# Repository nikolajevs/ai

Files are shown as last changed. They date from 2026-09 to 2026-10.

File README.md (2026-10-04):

# GrowBox — контроллер гроубокса

Прошивка ESP32 и собственная плата управления освещением, вентиляцией, поливом и обогревом. Температура и влажность измеряются внешним SHT4x; настройки доступны через веб-интерфейс, расписания используют RTC, журнал сохраняется на microSD.

## Структура репозитория

| Папка | Содержимое |
| --- | --- |
| [software/](software/README.md) | Прошивка Arduino для ESP32, веб-интерфейс и инструкция по сборке |
| [hardware/](hardware/README.md) | Проекты KiCad 10, BOM, модели деталей, корпус и файлы изготовления |
| [tests/](tests/) | Автоматические тесты веб-интерфейса |
| [vps-docs/](vps-docs/README.md) | Инструкция по работе с удалённой KiCad-станцией |

## Аппаратная часть

- [PCB_V1](hardware/PCB_V1/README.md) — основной проект платы: вход 24 В, четыре слоя, размер до 100×100 мм.
- [cheap-version](hardware/cheap-version/README.md) — вариант платы с использованием имеющихся компонентов. Файлы изготовления и состояние проверок описаны в его [FAB.md](hardware/cheap-version/FAB.md).
- [Корпус](hardware/enclosure/README.md) — параметрическая модель для 3D-печати; перед использованием сверяйте её с выбранной версией платы.

## Начало работы

Для прошивки откройте `software/software.ino`; зависимости, загрузка веб-интерфейса и проверки описаны в [software/README.md](software/README.md).

Для платы откройте нужный проект KiCad: `hardware/PCB_V1/PCB_V1.kicad_pro` или `hardware/cheap-version/cheap-version.kicad_pro`. Инструкции по проверкам и изготовлению находятся в документации соответствующего проекта.

Правила работы с репозиторием — [AGENTS.md](AGENTS.md).

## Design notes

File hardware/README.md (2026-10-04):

# Плата GrowBox

Проект KiCad 10: [PCB_V1/PCB_V1.kicad_pro](PCB_V1/PCB_V1.kicad_pro).
Текущая ревизия — **0.22**. Схема, размещение и трассировка выполнены; Gerber и заказной BOM подготовлены. Состояние проекта и навигация — [PCB_V1/README.md](PCB_V1/README.md).

## Проверки

Из папки `hardware`, с установленным KiCad 10:

```sh
python check_all.py
```

При нестандартной установке задайте `KICAD_CLI` (путь к `kicad-cli`) и `KICAD_PYTHON` (Python с модулем `pcbnew`). На Windows можно запускать через `"C:\Program Files\KiCad\10.0\bin\python.exe"`.

Проверяются ERC, соединения схемы и платы, размещение, правила трассировки, расчёты, BOM, DFM и DRC. Команда завершается ошибкой при нарушениях или несоединённых площадках. Сохранённые отчёты — [review/](review/).

`python check_all.py --write` обновляет отчёты, изображения листов и BOM. Используйте его только при намеренном обновлении этих файлов.

## Работа с готовой платой

- После изменения схемы обновляйте плату через **Update PCB from Schematic** в KiCad. `sync_board.py` предназначен для неразведённой платы и отказывается менять разведённую.
- После изменения платы выполните проверки и пересоберите производственный архив по [FAB.md](PCB_V1/FAB.md).
- Скрипты `route_power.py`, `route_signals.py`, `route_complete.py` пересоздают трассировку; это не обычная проверка. Зафиксированный результат — файл платы. Подробности — [ROUTING.md](PCB_V1/ROUTING.md).

## Инструменты

| Задача | Скрипты / инструкция |
|---|---|
| Все проверки | `check_all.py`; отдельные проверки — `verify_*.py`, `check_fab.py` |
| Расчёты питания и меди | `analyze_led_power.py`, `analyze_power_path.py`, `analyze_copper.py` |
| Заказ деталей и оценка цены | [BOM.md](PCB_V1/BOM.md), `export_lcsc_bom.py`, `audit_bom_cost.py`, `estimate_jlc_assembly.py` |
| Gerber и сверловка | [FAB.md](PCB_V1/FAB.md), `export_fab.py` |
| 3D-модели | `models3d/mechanical.py`, `models3d/power.py`, `sync_models.py`; [источники](PCB_V1/PLACEMENT.md) |
| Одноразовая плата из склада | [cheap-version/README.md](cheap-version/README.md) — отдельный проект cheap-1 (копия схемы PCB_V1 с заменами деталей) |
| Корпус (3D-печать) | [enclosure/README.md](enclosure/README.md), `enclosure/enclosure.py`, `enclosure/check_enclosure.py` |

Правила веток и проверки — [AGENTS.md](../AGENTS.md). Работа с удалённой KiCad-станцией — [vps-docs/README.md](../vps-docs/README.md).

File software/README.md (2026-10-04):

# GI — ESP32 Controller

Автоматизированная система управления гроубоксом на базе ESP32: климат-контроль, освещение, вентиляция, автополив и обогрев с веб-интерфейсом управления и облачной телеметрией.

Аппаратная часть: [плата PCB_V1](../hardware/PCB_V1/README.md) — схема, трассировка, заказ деталей и файлы изготовления. Общее описание — в [README репозитория](../README.md).

## Возможности

- **Климат-контроль** — датчик SHT4x (температура/влажность), поддержание заданной температуры с гистерезисом
- **Освещение** — управление LED по расписанию день/ночь, яркость связана с температурным контролем
- **Вентиляция** — два независимых канала PWM-управления вентиляторами (fan1/fan2) с настраиваемыми мин/макс пределами
- **Автополив** — планировщик по дням недели (битовая маска), защита от повторного срабатывания
- **Обогрев** — реле обогревателя с гистерезисом, три режима расписания: день/ночь/всегда
- **Безопасность** — аварийное отключение при потере связи с датчиком SHT4x, защита от деления на ноль в расчётах
- **Веб-интерфейс** — вкладки настроек, интерактивные SVG-графики с тултипами, статика лежит в SPIFFS
- **Хранение данных** — логирование в CSV на SD-карту, настройки — в NVS (Preferences)
- **Облако** — телеметрия в Ubidots по HTTPS через отдельную FreeRTOS-задачу на Core 0

## Структура проекта

```
software/
├── software.ino     # основная прошивка ESP32
└── data/            # файлы веб-интерфейса (SPIFFS/LittleFS)
    ├── index.html
    ├── settings.html
    ├── script.js
    ├── settings.js
    └── style.css
```

## Технологический стек

- ESP32 (Arduino framework, ядро esp32 3.x — используется `ledcAttach()` и `entry.path()`)
- ESPAsyncWebServer + AsyncTCP
- SPIFFS (веб-интерфейс из `software/data/`, заливается через Tools → ESP32 Sketch Data Upload)
- RTClib (PCF8563 на плате 0.20 или модуль DS3231 — определяется автоматически; планирование день/ночь)
- Adafruit SHT4x
- SD-карта (CSV-логирование)
- Ubidots (облачная телеметрия, HTTPS)

## Как устроены данные

Всё, что задаёт пользователь, лежит в `struct Settings`, всё, что происходит сейчас, — в `struct State`. Обе структуры — простые данные без `String`, и между задачами они передаются только целыми копиями под спинлоком:

- `Settings` меняет только обработчик `/save-settings`: разбирает форму в свою копию и публикует её целиком. `loop()` раз в секунду берёт свежую копию, задача Ubidots — перед каждой отправкой.
- `State` пишет только `loop()`, в свою рабочую копию `state`, и публикует её в конце каждой итерации. Веб и Ubidots читают `stateSnapshot()`.

Каждая настройка описана одной строкой в таблице `SETTING_DEFS`: имя в форме и JSON, ключ NVS, диапазон, значение по умолчанию. Из неё работают загрузка из NVS, разбор формы, сохранение и `/api/settings`. Чтобы добавить настройку, нужно поле в `Settings` и строка в таблице; если тип строки не совпадёт с типом поля, прошивка не соберётся.

Ключи NVS в таблице менять нельзя: по ним уже прошитые платы читают сохранённые значения.

## Веб-API

| Метод | Путь | Назначение |
|---|---|---|
| GET | `/api/status` | Текущее состояние (снимок `State`) |
| GET | `/api/settings` | Все настройки. Пароли и токен **не отдаются** — только флаги `wifi_pass_set` / `ap_pass_set` / `ubidots_token_set` |
| GET | `/api/console` | Кольцевой буфер сообщений Serial |
| GET | `/api/log?date=YYYY-MM-DD` | CSV-лог за день. Формат даты проверяется строго |
| GET | `/api/files` | Последние файлы в корне SD |
| POST | `/api/clearlogs` | Удаляет из корня SD файлы `*.csv`. Именно POST: GET-версию можно было вызвать со сторонней страницы |
| POST | `/save-settings` | Сохранение настроек. Пустое поле пароля/токена = «не менять»; стереть пароль — галочкой «сеть без пароля» |
| POST | `/set-time` | Установка часов. Применяется в `loop()`, к I2C обращается только он |

## Примечание по безопасности

Учётные данные WiFi и Ubidots хранятся в NVS Preferences. В исходниках нет рабочих паролей и токенов. Все страницы и API требуют входа `admin` с индивидуальным паролем устройства (HTTP Digest). Изменяющие запросы дополнительно требуют CSRF-токен; очистка SD доступна только через POST.

Сохранённые пароли и токен не возвращаются через API. Пустое поле пароля/токена означает «оставить прежнее значение». Для открытой сети роутера и отключения облака есть отдельные флажки удаления секрета. Точка доступа самой платы всегда защищена паролем.

Ubidots использует HTTPS с проверкой сертификата через ISRG Root X1. Для проверки срока сертификата плата синхронизирует системное UTC-время через NTP; это не изменяет локальное расписание DS3231. При недоступности доверенного TLS-соединения данные не отправляются; небезопасного fallback нет. Корневой сертификат находится в `software/UbidotsCA.h` и может требовать обновления при смене цепочки сервера.

Локальный веб-интерфейс остаётся HTTP: Digest не шифрует содержимое страниц и форм. Используйте защищённую точку доступа/доверенную LAN, не публикуйте порт 80 в Интернет.

### Обновление существующего устройства

1. Прошейте `software/software.ino` и обязательно обновите файлы SPIFFS из `software/data/`: старый интерфейс не передаёт CSRF-токен.
2. Откройте USB Serial Monitor, 115200 бод, и перезагрузите плату. В USB-консоли появятся `AP password` и `Web login: admin / ...`. Эти строки не попадают в веб-журнал.
3. При первом запуске этой версии пароль точки доступа заменяется случайным. Переподключитесь с паролем из USB-консоли и войдите в браузере. Пароли сохраняются между перезагрузками.
4. Ранее опубликованные пароль роутера и токен Ubidots необходимо заменить у соответствующих провайдеров и в настройках платы. Удаление из текущего файла не отзывает секреты и не удаляет их из истории Git. Существующие значения в NVS сохраняются до явной замены пользователем.
5. Проверьте дату/время. При потере питания RTC, неверной дате или отсутствии часов при старте автополив блокируется до установки времени или восстановления валидного RTC. После последующего отказа часов используется резервный отсчёт от последнего корректного времени.

На чистом NVS обогрев выключен. Существующий выбранный пользователем режим сохраняется.

Генерируемые пароли администратора и точки доступа состоят из **8 символов** (цифры и заглавные латинские буквы без похожих `0`, `1`, `I`, `O`). При обновлении длинный пароль администратора заменяется; пароль AP старого формата — ровно 32 строчные шестнадцатеричные цифры — заменяется однократно. Это распознавание по формату: вручную заданный пароль того же формата также будет заменён. Остальные пользовательские пароли AP сохраняются. Новые значения видны в USB-консоли, повторного сброса при перезагрузке нет. CSRF-токен сохраняет прежнюю длину.

Настройки света находятся на отдельной вкладке «Освещение».

Полив измеряет длительность через `millis()`, включая его переполнение; изменение календарного времени или настроек длительности не меняет уже запущенный цикл. День запуска записывается в NVS **до** включения насоса. При ошибке записи насос не включается. После перезапуска прерванный полив не возобновляется и не повторяется в тот же день. При переводе даты назад новые поливы запрещены до дня, следующего за последней сохранённой отметкой.

### Сборка и проверки

Целевая конфигурация: двухъядерный ESP32 Dev Module, Arduino-ESP32 **3.3.8**. Arduino core 2.x не поддерживается (используется LEDC API 3.x).

Библиотеки проверяемой сборки:

- ESP Async WebServer 3.11.0, Async TCP 3.4.10;
- RTClib 2.1.4;
- Adafruit SHT4x Library 1.0.5, Adafruit BusIO 1.17.4, Adafruit Unified Sensor 1.1.15.

Команды выполняются из корня репозитория:

```sh
arduino-cli compile --fqbn esp32:esp32:esp32 software
node --test tests/settings.test.cjs
```

Каждая сборка автоматически выполняет compile-time проверки календаря, флагов потери питания DS3231 (OSF) и PCF8563 (VL), BCD и режимов 12/24 часа, резервного отсчёта, переполнения `millis()` и допуска полива из `SafetyTests.h`, без затрат памяти/времени на плате. Тесты интерфейса проверяют скрытие секретов, передачу CSRF во всех формах и POST при очистке.

После прошивки отдельно проверьте на стенде: отключение RTC во время работы; потерю его батарейки; перевод времени во время полива; перезагрузку в минуту полива; сохранение SSID с кавычкой; отказ в API без входа/CSRF. Проверка сборки не заменяет эти аппаратные проверки.

---

V.1

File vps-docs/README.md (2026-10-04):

# KiCad VPS workstation

Удалённая рабочая станция для репозитория `nikolajevs/ai`.

## VPS

- Ubuntu Server 24.04 LTS 64-bit
- 2 CPU cores
- 4 GB RAM
- 4 GB swap
- ~63 GB SSD
- 100 Mbps
- KiCad 10.0.6
- XFCE / X11
- TigerVNC
- noVNC
- Tailscale
- Git
- Python 3

На VPS также работает Telegram-бот `ss-bot` (Node.js/PM2). Сайты `my-app` и `todo-app` установлены, но выключены ради экономии ресурсов — см. раздел [Telegram-бот и PM2](#telegram-бот-и-pm2).

## Текущий режим: без графики

С 2026-09-29 VPS работает без графической среды: `kicad-vnc` и `kicad-novnc` остановлены и убраны из автозапуска, Tailscale Serve для noVNC снят. Это освобождает около 200 MB RAM в простое и убирает пики до ~2 GB, когда в VNC-сессии открывался KiCad.

Проверки проекта (`kicad-cli`, `check_all.py`) дисплей не требуют и работают как обычно. Разделы ниже про VNC/noVNC описывают конфигурацию на случай, если графика снова понадобится.

Включить графику обратно:

```bash
sudo systemctl enable --now kicad-vnc.service kicad-novnc.service
sudo tailscale serve --bg localhost:6080
```

Выключить снова:

```bash
sudo systemctl disable --now kicad-novnc.service kicad-vnc.service
sudo tailscale serve reset
sudo systemctl reset-failed kicad-vnc kicad-novnc
```

`reset-failed` убирает косметический статус `failed`: при остановке noVNC выходит с кодом 143, а `tigervncserver -kill` — с кодом 1, если X-сервер уже завершился.

---

## Архитектура

```text
Phone / PC
    |
    | HTTPS через Tailscale
    v
Tailscale Serve
    |
    v
noVNC 127.0.0.1:6080
    |
    v
TigerVNC 127.0.0.1:5901
    |
    v
XFCE / X11
    |
    v
KiCad 10
```

Порты `5901` и `6080` должны слушать только localhost и не должны быть открыты в публичный интернет.

Tailscale Funnel для KiCad не используется.

---

# Удалённый рабочий стол

## Проверка сервисов

```bash
systemctl status kicad-vnc.service --no-pager
systemctl status kicad-novnc.service --no-pager
```

Проверка портов:

```bash
ss -ltnp | grep -E '5901|6080'
```

Ожидается примерно:

```text
127.0.0.1:5901
127.0.0.1:6080
```

## Перезапуск

```bash
sudo systemctl restart kicad-vnc.service
sudo systemctl restart kicad-novnc.service
```

## Логи

```bash
sudo journalctl -u kicad-vnc.service -n 100 --no-pager
sudo journalctl -u kicad-novnc.service -n 100 --no-pager
```

---

# TigerVNC

Сервис:

```text
/etc/systemd/system/kicad-vnc.service
```

Конфигурация:

```ini
[Unit]
Description=KiCad XFCE TigerVNC desktop
After=network.target

[Service]
Type=oneshot
User=administrator
RemainAfterExit=yes
ExecStart=/usr/bin/tigervncserver :1 -localhost yes -geometry 1600x900 -depth 24
ExecStop=/usr/bin/tigervncserver -kill :1

[Install]
WantedBy=multi-user.target
```

XFCE startup:

```text
~/.vnc/xstartup
```

Содержимое:

```sh
#!/bin/sh

unset SESSION_MANAGER
unset DBUS_SESSION_BUS_ADDRESS

export XDG_SESSION_TYPE=x11
export XDG_CURRENT_DESKTOP=XFCE

exec dbus-launch --exit-with-session startxfce4
```

VNC password задаётся:

```bash
vncpasswd
```

---

# noVNC

Сервис:

```text
/etc/systemd/system/kicad-novnc.service
```

Конфигурация:

```ini
[Unit]
Description=KiCad noVNC web interface
After=kicad-vnc.service
Requires=kicad-vnc.service

[Service]
Type=simple
User=administrator
ExecStart=/usr/share/novnc/utils/novnc_proxy --listen 127.0.0.1:6080 --vnc 127.0.0.1:5901
Restart=on-failure
RestartSec=3

[Install]
WantedBy=multi-user.target
```

---

# Tailscale

Проверка:

```bash
tailscale status
tailscale ip -4
sudo tailscale serve status
```

noVNC публикуется только внутри tailnet:

```bash
sudo tailscale serve --bg localhost:6080
```

Доступ осуществляется по адресу вида:

```text
https://<hostname>.<tailnet>.ts.net/vnc.html
```

Tailscale Funnel не включать.

---

# KiCad

Версия:

```bash
kicad-cli version
```

Текущая установленная версия:

```text
10.0.6
```

Основной проект:

```text
~/kicad/main/hardware/PCB_V1/PCB_V1.kicad_pro
```

Запуск KiCad из SSH в существующей VNC-сессии (только когда графика включена):

```bash
DISPLAY=:1 kicad \
  ~/kicad/main/hardware/PCB_V1/PCB_V1.kicad_pro \
  >/tmp/kicad.log 2>&1 &
```

Проверка:

```bash
pgrep -a kicad
```

KiCad специально не запускается автоматически после reboot, чтобы экономить RAM.

## Глобальные таблицы библиотек

В проекте подключена только библиотека `GrowBox`, а стандартные библиотеки KiCad (`Device`, `power`, `Resistor_SMD`, `Capacitor_SMD` и т.д.) берутся из глобальных таблиц:

```text
~/.config/kicad/10.0/sym-lib-table
~/.config/kicad/10.0/fp-lib-table
```

Обычно их создаёт GUI KiCad при первом запуске. На VPS, где сначала использовался только `kicad-cli`, их нужно скопировать из шаблонов один раз:

```bash
cp --update=none \
  /usr/share/kicad/template/sym-lib-table \
  /usr/share/kicad/template/fp-lib-table \
  ~/.config/kicad/10.0/
```

Проверка:

```bash
ls -l ~/.config/kicad/10.0/*lib-table
```

Если таблиц нет, ERC выдаёт сотни ложных предупреждений `lib_symbol_issues` / `footprint_link_issues`, а DRC — `lib_footprint_issues` с текстом `The current configuration does not include the ... library`. В этом случае `check_all.py` завершается с ошибкой `ENVIRONMENT` и сообщением `KiCad library tables`: это проблема настройки машины, а не нарушения проекта.

---

# Проверка проекта

Основной скрипт:

```text
hardware/check_all.py
```

Запуск:

```bash
cd ~/kicad/main/hardware

KICAD_CLI=/usr/bin/kicad-cli \
KICAD_PYTHON=/usr/bin/python3 \
python3 check_all.py
```

`check_all.py` выполняет в том числе:

- ERC;
- экспорт netlist;
- `verify_netlist.py`;
- электрические расчётные проверки;
- проверку BOM;
- проверку PCB, разводки и технологичности (JLCPCB);
- DRC.

Ожидаемый результат: `ALL CHECKS PASSED`, exit code `0`; ERC 0 нарушений, DRC 0 нарушений и 0 неподключённых падов (плата разведена); `verify_routing.py` входит в запуск. Перед первым запуском на новой машине настройте глобальные таблицы библиотек (см. раздел KiCad выше).

Для обновления committed review-файлов:

```bash
python3 check_all.py --write
```

`--write` использовать только намеренно, когда нужно обновить артефакты проекта.

---

# GitHub

Репозиторий:

```text
nikolajevs/ai
```

SSH remote:

```text
git@github-ai:nikolajevs/ai.git
```

Основной checkout на VPS:

```text
~/kicad/main
```

Рабочие деревья:

```text
~/kicad/worktrees/
```

GitHub остаётся источником истины.

---

# SSH для GitHub

Для `nikolajevs/ai` используется отдельный SSH deploy key.

Alias:

```text
github-ai
```

Фрагмент `~/.ssh/config`:

```text
Host github-ai
    HostName github.com
    User git
    IdentityFile ~/.ssh/id_ed25519_ai
    IdentitiesOnly yes
```

Проверка:

```bash
ssh -T git@github-ai
```

Ожидается:

```text
Hi nikolajevs/ai! You've successfully authenticated...
```

Private SSH key никогда не коммитить в репозиторий.

---

# Git workflow для AI

Основной принцип:

```text
origin/main
    |
    +--- новая task branch
            |
            +--- ChatGPT / Claude
            +--- изменения
            +--- проверки
            +--- commit
            +--- push
            +--- review
            +--- merge
                    |
                    v
                  main
```

AI не должен работать непосредственно в `main`.

Одна задача = одна ветка.

Для параллельной работы желательно использовать отдельный Git worktree для каждой ветки.

Это особенно важно для:

```text
*.kicad_sch
*.kicad_pcb
```

Сложные merge conflicts в этих файлах не следует разрешать автоматически без визуальной проверки.

---

# Обновить main

```bash
cd ~/kicad/main

git fetch origin --prune
git switch main
git pull --ff-only
```

Рекомендуемые настройки:

```bash
git config pull.ff only
git config fetch.prune true
```

---

# Создать новую рабочую ветку

Пример:

```bash
cd ~/kicad/main

git fetch origin --prune
git switch main
git pull --ff-only

git worktree add \
  -b ai/layout-led \
  ~/kicad/worktrees/ai__layout-led \
  origin/main
```

Рабочий каталог:

```text
~/kicad/worktrees/ai__layout-led
```

---

# Подключить ветку, уже созданную AI на GitHub

Сначала:

```bash
cd ~/kicad/main
git fetch origin --prune
```

Затем:

```bash
git worktree add \
  --track \
  -b ai/layout-led \
  ~/kicad/worktrees/ai__layout-led \
  origin/ai/layout-led
```

Если локальная ветка уже существует:

```bash
git worktree add \
  ~/kicad/worktrees/ai__layout-led \
  ai/layout-led
```

---

# Список worktree

```bash
git -C ~/kicad/main worktree list
```

---

# Проверить AI-ветку

Пример:

```bash
cd ~/kicad/worktrees/ai__layout-led/hardware

KICAD_CLI=/usr/bin/kicad-cli \
KICAD_PYTHON=/usr/bin/python3 \
python3 check_all.py
```

---

# Открыть AI-ветку в KiCad

```bash
DISPLAY=:1 kicad \
  ~/kicad/worktrees/ai__layout-led/hardware/PCB_V1/PCB_V1.kicad_pro \
  >/tmp/kicad-ai-layout-led.log 2>&1 &
```

Не следует одновременно редактировать одну и ту же ветку из нескольких открытых KiCad-сессий.

---

# После merge ветки

Обновить main:

```bash
cd ~/kicad/main
git fetch origin --prune
git switch main
git pull --ff-only
```

Удалить старый worktree:

```bash
git worktree remove ~/kicad/worktrees/ai__layout-led
git worktree prune
```

Удалить локальную ветку после merge:

```bash
git branch -d ai/layout-led
```

---

# Ресурсы VPS

Быстрая проверка:

```bash
free -h
swapon --show
df -h /
uptime
```

Процессы по RAM:

```bash
ps aux --sort=-%mem | head -15
```

Интерактивный мониторинг:

```bash
htop
```

---

# Swap

На сервере используется:

```text
4 GB RAM
4 GB swap
```

Проверка:

```bash
free -h
swapon --show
```

Параметр:

```text
vm.swappiness=10
```

---

# Контроль диска

Проверить filesystem:

```bash
df -h /
```

Крупные каталоги:

```bash
sudo du -xhd1 / 2>/dev/null | sort -h
sudo du -xhd1 /home/administrator 2>/dev/null | sort -h
```

Файлы больше 500 MB:

```bash
sudo find /home/administrator \
  -xdev \
  -type f \
  -size +500M \
  -printf '%s %p\n' 2>/dev/null \
  | sort -n \
  | numfmt --field=1 --to=iec
```

---

# Telegram-бот и PM2

Node.js установлен через `nvm`. В неинтерактивных shell (systemd, агенты, `ssh host cmd`) `pm2` может отсутствовать в `PATH`, поэтому используется полный путь:

```bash
export PATH=/home/administrator/.nvm/versions/node/v24.21.0/bin:$PATH
```

## Приложения

| PM2 name | Путь | Статус |
|---|---|---|
| `ss-bot` | `/opt/SS_COM/src/index.js` | запущен, в автозапуске |
| `pm2-logrotate` | модуль PM2 | запускается вместе с PM2 |
| `my-app` | `/home/administrator/BRIDGE/server/index.js` | выключен |
| `todo-app` | `/home/administrator/todo-app/server.js` | выключен |

Бот читает `BOT_TOKEN` и остальные настройки из `/opt/SS_COM/.env` сам; SQLite — встроенный `node:sqlite` Node 24, пересборка `better-sqlite3` не нужна. Деплой бота описан в `/opt/SS_COM/DEPLOY.md`.

## Автозапуск

PM2 запускается systemd-сервисом `pm2-administrator.service` (создан через `pm2 startup`), который после reboot восстанавливает список из `~/.pm2/dump.pm2`. Сейчас в нём только `ss-bot`.

```bash
systemctl status pm2-administrator --no-pager
pm2 status
pm2 logs ss-bot --lines 50 --nostream
```

Процессы PM2 должны принадлежать `pm2-administrator.service`:

```bash
ps -eo pid,cgroup:50,args | grep -E 'God Daemon|SS_COM' | grep -v grep
```

Если `pm2` запустить вручную из сессии агента (например, `claude-remote.service`) при остановленном сервисе, демон окажется внутри этой сессии и погибнет при её перезапуске (`KillMode=control-group`). Правильный перезапуск:

```bash
pm2 kill
sudo systemctl start pm2-administrator
```

Сервис привязан к `~/.nvm/versions/node/v24.21.0`. Если эту версию Node удалить или сменить, нужно заново выполнить `pm2 startup` (он выведет команду с `sudo`) и `pm2 save`.

## Вернуть сайты

Список процессов до выключения сайтов сохранён в:

```text
~/.pm2/dump.pm2.before-ss-bot-20260929-164457
```

Запустить сайт и добавить его в автозапуск:

```bash
cd /home/administrator/todo-app && pm2 start server.js --name todo-app
cd /home/administrator/BRIDGE/server && pm2 start index.js --name my-app
pm2 save
```

`todo-app` и `ss-bot` работали на Node 24.21.0, `my-app` — на 24.18.0.

---

# PM2 logs

На VPS уже была проблема, когда PM2 logs заняли около 40 GB.

Главные файлы были:

```text
~/.pm2/pm2.log
~/.pm2/logs/my-app-error.log
```

Проверка:

```bash
du -sh ~/.pm2
du -sh ~/.pm2/logs
ls -lh ~/.pm2/logs
```

Очистить конкретный огромный лог без удаления файла:

```bash
truncate -s 0 ~/.pm2/logs/<application>-error.log
```

PM2 log:

```bash
truncate -s 0 ~/.pm2/pm2.log
```

---

# PM2 log rotation

Модуль `pm2-logrotate` уже установлен и запускается вместе с PM2. Проверить настройки:

```bash
pm2 conf pm2-logrotate
```

Первичная установка:

```bash
pm2 install pm2-logrotate

pm2 set pm2-logrotate:max_size 50M
pm2 set pm2-logrotate:retain 7
pm2 set pm2-logrotate:compress true
```

---

# Node.js / better-sqlite3

На VPS уже возникала ошибка ABI:

```text
better_sqlite3.node was compiled against a different Node.js version
ERR_DLOPEN_FAILED
```

В результате PM2 постоянно перезапускал приложение и быстро увеличивал error log.

Исправление:

```bash
pm2 stop <application>

cd <application-directory>
npm rebuild better-sqlite3

pm2 start <application>
```

Если не хватает build tools:

```bash
sudo apt install -y build-essential python3 make g++
```

---

# TigerVNC: display :1 already running

Ошибка:

```text
A X11 server is already running for display :1
```

Проверить реальные процессы:

```bash
pgrep -af 'Xtigervnc|Xorg|Xvnc|Xwayland'
sudo ss -ltnp | grep 5901
```

Проверить lock:

```bash
ls -l /tmp/.X1-lock /tmp/.X11-unix/X1 2>/dev/null
```

Если `Xtigervnc` действительно жив, сначала остановить процесс:

```bash
kill -TERM <PID>
sleep 2
```

Проверить:

```bash
ps -p <PID>
ss -ltnp | grep 5901
```

Только после остановки процесса можно удалить stale lock/socket:

```bash
sudo rm -f /tmp/.X1-lock
sudo rm -f /tmp/.X11-unix/X1
```

Затем:

```bash
sudo systemctl reset-failed kicad-vnc.service
sudo systemctl start kicad-vnc.service
```

---

# noVNC не открывается

Проверить:

```bash
systemctl status kicad-novnc.service --no-pager
ss -ltnp | grep 6080
```

Проверить backend VNC:

```bash
ss -ltnp | grep 5901
```

Проверить Tailscale:

```bash
tailscale status
sudo tailscale serve status
```

---

# KiCad AT-SPI warning

Предупреждение вида:

```text
AT-SPI: Error retrieving accessibility bus address
```

в VNC/XFCE-сессии само по себе не означает сбой KiCad.

Проверить процесс:

```bash
pgrep -a kicad
```

---

# systemd после reboot

Проверить:

```bash
systemctl status pm2-administrator --no-pager
pm2 status
tailscale status
```

Если графика включена, дополнительно:

```bash
systemctl status kicad-vnc.service --no-pager
systemctl status kicad-novnc.service --no-pager
sudo tailscale serve status
```

---

# Основные правила безопасности

1. Не открывать VNC `5901` в публичный интернет.
2. Не открывать noVNC `6080` в публичный интернет.
3. Не использовать Tailscale Funnel для KiCad.
4. Не коммитить SSH private keys.
5. Не коммитить VNC passwords.
6. Не коммитить GitHub tokens.
7. Не коммитить Tailscale credentials.
8. AI работает только через отдельные ветки.
9. `main` обновляется из GitHub после merge.
10. Перед merge KiCad-изменений запускать проверки проекта.
11. Сложные конфликты `.kicad_sch` и `.kicad_pcb` проверять визуально.

---

# Краткая памятка

Обновить проект:

```bash
cd ~/kicad/main
git fetch origin --prune
git switch main
git pull --ff-only
```

Проверить VPS:

```bash
free -h
df -h /
```

Проверить бота:

```bash
systemctl status pm2-administrator --no-pager
pm2 status
```

Проверить Tailscale:

```bash
tailscale status
```

Проверить KiCad:

```bash
kicad-cli version
```

Запустить KiCad (только когда графика включена, см. «Текущий режим: без графики»):

```bash
DISPLAY=:1 kicad \
  ~/kicad/main/hardware/PCB_V1/PCB_V1.kicad_pro \
  >/tmp/kicad.log 2>&1 &
```

Проверить проект:

```bash
cd ~/kicad/main/hardware
KICAD_CLI=/usr/bin/kicad-cli KICAD_PYTHON=/usr/bin/python3 python3 check_all.py
```

---

# AI launchers

На VPS установлены OpenAI Codex CLI и Claude Code.

Безопасный запуск выполняется через wrapper-команды:

```bash
ai-codex <branch>
ai-claude <branch>
```

Примеры:

```bash
ai-codex ai/power-fix
ai-claude ai/layout-led
```

Wrapper:

- обновляет ветки через `git fetch`;
- запрещает работу напрямую в `main`;
- создаёт отдельный worktree в `~/kicad/worktrees/`;
- использует существующую ветку, если она уже есть;
- иначе создаёт новую ветку от `origin/main`;
- запускает агента внутри его worktree.

Codex и Claude могут работать параллельно только в разных ветках/worktree.

После запуска агент должен прочитать `AGENTS.md` и `vps-docs/README.md`.

Проверка KiCad из worktree:

```bash
cd hardware
KICAD_CLI=/usr/bin/kicad-cli \
KICAD_PYTHON=/usr/bin/python3 \
python3 check_all.py
```

Перед push:

```bash
git status
git diff
git push -u origin HEAD
```

После merge worktree можно удалить:

```bash
git -C ~/kicad/main worktree remove ~/kicad/worktrees/<worktree>
git -C ~/kicad/main worktree prune
```

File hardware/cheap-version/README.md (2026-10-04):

# cheap-version — одноразовая плата из того, что есть

Версия **cheap-1** платы GrowBox: те же функции и прошивка, что у PCB_V1 (ревизия 0.22), но детали берутся со склада пользователя, докупается только недостающее. Это отдельный проект, а не ревизия PCB_V1: `../PCB_V1/` не меняется.

**Решения пользователя (03.10.2026):** основа — копия схемы PCB_V1 с заменами; плата 4 слоя, 100×100 мм, стек как у PCB_V1 (1,6 мм, 1 oz снаружи / 0,5 oz внутри); ESP32-WROOM-32E на плате, прошивка и GPIO без изменений; J901 — винтовой клеммник KF301 вместо XT60, защиты от переполюсовки не нужно; L711 — Feryster DTMSS-27/0.047/15-V **на плате стоймя** (корпус будет выше); выходные 10 мкФ 100 В X7S докупаются, как в V1 (4,7 мкФ X7R со склада не берём).

**Решения пользователя (04.10.2026):** CH1 рассчитан на **80 Вт** (R716 0,12 Ом вместо 0,18; LED-панель допускает до 120 Вт, плата её не догружает), драйвер нагревателя — снова **UCC27524ADR** (как в V1) вместо IRS4427S, затем шина +12V и шелкография.

## Состояние

- **Схема готова к проверке** (`cheap-version.kicad_sch` + 6 листов). Её строит `tools/make_cheap1.py` из `../PCB_V1/` (от базовой схемы каждый раз заново). Остальные инструменты: `tools/sch_edit.py` — редактор текста схем, `tools/netdiff.py` — сравнение связности с PCB_V1, `tools/make_footprints.py` — свои футпринты (запуск Python из KiCad), `tools/make_models3d.py` — их 3D-модели (CadQuery), `tools/analyze_led_cheap.py` — расчёт LED-boost. После ручных правок схемы в KiCad `make_cheap1.py` больше не запускать.
- ERC: **0 нарушений**. Связность у всех нетронутых выводов совпадает с PCB_V1 (`netdiff.py`: 0 различий).
- Свои футпринты и упрощённые 3D: `Diodes_PowerDI5`, `L_Feryster_DTMSS-27_V` (`libraries/`). BOM — `BOM_cheap1.csv`, `BUY_cheap1.csv` (см. ниже).
- **Плата `cheap-version.kicad_pcb` разведена, Gerber и сверловка выгружены; перед заказом остаются пункты ([FAB.md](FAB.md)).** 170 деталей, 4 слоя 100×100 мм; 0 пересечений courtyard и выходов за контур; все цепи соединены. ERC 0; DRC (с `.kicad_dru`) 0 нарушений, 0 замечаний, 0 неподключённых; `check_fab.py` 0 FAIL / 2 WARN; `tools/run_checks.py` 9 из 9. Силовая медь входа, PTC, +24V к LED и узлов каналов усилена, линия вентиляторов +12V расширена, добавлен C911 у U902, шелкография очищена (см. ниже). JLCDFM (04.10.2026): единственное правило с Danger — зазор сквозных площадок до SMD-площадок (сборочное, платы не касается), остальное предупреждения, разбор в [FAB.md](FAB.md), раздел 6. Остаются: измерения на макете и корпус.
- Склад: [stock/components-20261003.csv](stock/components-20261003.csv); в схеме поле `Source` = `stock:<id>`, у покупных деталей пусто. Даташиты — [datasheets/](datasheets/README.md) (PDF в git не хранятся).

## Что заменено

| Блок | PCB_V1 | cheap-1 | Склад (id, шт) |
|---|---|---|---|
| 24→12 В (U902) | LMR16020PDDAR | **ST1S14PHR**; R906 (RT) убран | 26: 3 |
| 12→3,3 В (U101) | TPS54202DDCR | **ST1S10PHR**; L101 4,7 мкГн (FXL0630-4R7-M, тот же корпус); R102 31,6 кОм; C103 — не BOOT, а VIN_A (2,2 мкФ) | 27: 4 |
| Нагреватель PTC | UCC27524ADR, NTMFS5C628NL | драйвер **UCC27524ADR как в V1** (ENA на +12V, ENB на GND; было IRS4427S, 04.10.2026), **IRL2505** TO-220 | — (покупается); 78: 1 |
| LED-boost, ключи Q711/Q721 | AOD66923 | **BSC146N10LS5** (TDSON-8-1) | 112: 2 |
| LED-boost, диоды D711/D721 | SS5P10 | **SBRT15U100SP5** (PowerDI5, `GrowBox:Diodes_PowerDI5`) | 8: 5 |
| LED-boost, дроссель L711 | SRP1770TA-470M | **DTMSS-27/0.047/15-V** стоймя (`GrowBox:L_Feryster_DTMSS-27_V`) | 12: 1 |
| Диоды D521, D902 | SS36 | **SS56** (тот же SMC) | 20: 45 |
| Прочая керамика | см. BOM | 10 мкФ 50 В 1210 (C521, C710, C715, C725, C905, C906); 10 мкФ 35 В 1210 (C101, C602, C910); 22 мкФ 10 В 0805 (C104, C105, C401); 2,2 мкФ 16 В 0805 (C103, C203, C302); 10 мкФ 16 В 0805 (C201); 2,2 мкФ 50 В 1206 (C711, C721, C902); 100 нФ 0603 | 47+44; 6; 7; 57; 58; 3; 54 |
| Электролиты | C901 220 мкФ 50 В, C909 100 мкФ полимер | C901 **EEVFK1J471M** 470 мкФ 63 В (Ø16×16,5, футпринт CP_Elec_16x17.5); C909 **EEEFT1E821AP** 820 мкФ 25 В (Ø10) | 13: 1; 14: 1 |
| Резисторы | 0603 | 100 кОм/1 кОм 1 % 0603 (id 55, 62); 10 кОм, 4,7 кОм 0805 (id 70, 59, 72); 10 Ом и 47 кОм 1206 (id 41, 61) | см. CSV |
| Разъёмы | XT60PW-M, DORABO 3,5, KANGNEX 5,08, JST XH, TS-1187A | J901, J711/J721/J731: KF301-5,0-2P (MKDS-1,5-2 5,0); J302/J521/J601: FS1.5-02 3,5 мм; J501/J511: KF2510 4P (Molex KK-254); J301: XH угловой; SW201/SW202: тактовые 6×6×10 | 93; 86; 87; 90; 95 |

Остаётся как в V1 и докупается: UCC27524ADR (C185857, минимум 5 шт), шунт R716 0,12 Ом 2512 (FRM252WFR120TM той же серии, что был 0,18 Ом; номер на LCSC проверить), 7× Murata GRM32EC72A106KE05L (10 мкФ 100 В X7S, выходы LED), ESP32-WROOM-32E, PCF8563T и кварц, 2× AL8853S-13, microSD и держатель CR2032, TVS SMBJ26CA, предохранители и держатель F902, SOT-23 MOSFET, ESD-диоды, дроссели L721 и L902 и FXL0630-4R7-M, шунты, точные и мелкие резисторы и конденсаторы.

## Расчёты и проверка по даташитам

**ST1S14 (24→12 В).** Вход 5,5–48 В, VFB 1,222 В (1,202–1,239), предел тока 3,7–5,2 А, 850 кГц, BOOT 100 нФ, EN1 активный низкий (на GND), EN2 активный высокий (выше 1,5 В), PG не используется. Делитель R904 88,7 кОм 0,1 % + R905 10 кОм 0,1 %: 12,06 В, диапазон 11,9–12,2 В. L902 22 мкГн: пульсация 0,29–0,33 А, пик при 2 А — 2,17 А. EN2 через R907 470 кОм / R908 47 кОм: 1,96 В при 21,6 В, включение гарантировано от 16,5 В. Выходной электролит 820 мкФ (ESR 60 мОм): нуль 3,2 кГц, пульсация около 20 мВ; даташит допускает такие конденсаторы (fZ < BW < fSW/5), устойчивость проверить на макете.

**ST1S10 (12→3,3 В, DocID13844 Rev 7).** Выводы: 1 VIN_A, 2 INH (активный высокий; к VIN_A, если не нужен), 3 VFB, 4 AGND, 5 SYNC (на GND — 900 кГц), 6 VIN_SW, 7 SW, 8 PGND, EP — земля; вход до 18 В, VFB 0,8 В (0,784–0,816), предел тока 5 А, синхронный, диода нет. Делитель 100 кОм / 31,6 кОм: 3,33 В (3,26–3,40 В). Ток при бюджете 1 А: D = 0,28, пульсация 0,59 А на L 4,7 мкГн (диапазон даташита 0,6–1,2 А для 3 А), пик 1,3 А. Даташит проектирует контур под L 3,3 мкГн и C 22 мкФ (18,7 кГц); у cheap-1 L 4,7 мкГн и около 40 мкФ эффективных (3×22 мкФ 10 В): 11,6 кГц, нужна проверка реакции на скачок нагрузки. На входе по рекомендации для выходной ёмкости 47–100 мкФ: VIN_SW 10 мкФ (C101) и VIN_A 2,2 мкФ (C103). Потери около 0,37 Вт, нагрев около 15 К.

**Нагреватель.** Драйвер UCC27524ADR, как в PCB_V1 (IRS4427S убран 04.10.2026: его вход «1» от 2,5 В при минимуме 2,64 В у ESP32 давал запас всего 0,14 В). Выводы: 1 ENA (на +12V; в V1 на +3V3, но рядом нет места под переходное, даташит допускает неиспользуемый ENx на VDD, и внутренняя подтяжка к VDD всё равно держит канал включённым), 2 INA (HEATER_EN), 3 GND, 4 INB (GND), 5 OUTB (не подключён), 6 VDD (+12V), 7 OUTA (HEATER_DRIVE), 8 ENB (GND, канал B выключен). Входы по даташиту не зависят от VDD и рассчитаны на логику 3,3 В; затвор держит R602 100 кОм. IRL2505 при 4,2 А (100 Вт / 24 В): около 0,14 Вт без радиатора; 55 В выше ограничения входной TVS 42 В.

**LED-boost** (`tools/analyze_led_cheap.py`, результат — [review/LED_power_cheap1.txt](review/LED_power_cheap1.txt); модель PCB_V1, заменены только дроссель CH1, диоды и ключи). Все проверки модели проходят. **CH1 на 80 Вт** (R716 0,12 Ом, ток панели до 1,73 А с допусками): ток входа до 4,61 А, пик дросселя до 6,26 А (V1 при 53 Вт — 5,18 А; DTMSS держит 15 А), запас до OCP 2,06 А (R715 остаётся 0,027 Ом: окно OCP 8,3…14,1 А не выше точки 15 А дросселя), RMS дросселя 4,7 А, потери в диоде до 0,96 Вт, в обмотке 0,32 Вт без сердечника, субгармоники 0,18; консервативная оценка пульсации выхода 2,4 Vpp (при 53 Вт 1,6). Потолок канала на этом контроллере и дросселе: около 96 Вт (R716 0,10 Ом, запас OCP 1,13 А); при 120 Вт (R716 0,08 Ом) пик 8,57 А выше нижней границы OCP 8,32 А, канал начнёт упираться в ограничение — поэтому панель на 120 Вт подключается, но работает на 80 Вт. Предохранитель F711 (6,3 А, около 73 % от максимума входного тока) остаётся. CH2 без изменений (запас 0,97 А); выходная ёмкость как в V1. DTMSS-27 (даташит Feryster): 45,5 мкГн при 1 А, около 42 мкГн при 5 А, 26,1 мкГн при 15 А, RDC 10 мОм; в расчёте L = 47 мкГн −20 % и ещё −12 % на пике. BSC146N10LS5: RDS(on) 12,2 мОм типично, 14,6 мОм максимум при 10 В (у AOD66923 11 мОм); Qg 7,6 нКл, Qgd 2,8 нКл (3,5 нКл у AOD66923); выводы S1–S3, G4, D5–8, как в символе.

## Плата: как получено размещение

```sh
python tools/make_cheap1.py                                     # схема
kicad-cli sch export netlist --format kicadxml -o netlist.xml cheap-version.kicad_sch
"C:/Program Files/KiCad/10.0/bin/python.exe" tools/make_board.py netlist.xml      # плата из PCB_V1 без меди, футпринты заменены на месте
"C:/Program Files/KiCad/10.0/bin/python.exe" tools/auto_place.py --steps 80000 --seed 4 --write
"C:/Program Files/KiCad/10.0/bin/python.exe" tools/placement_report.py            # пересечения courtyard и выход за контур
```

`make_board.py` переносит позиции PCB_V1 (55 заменённых футпринтов остаются на своих местах), убирает R906 и обновляет цепи. `auto_place.py` — отжиг по габаритам courtyard (Python из KiCad только читает и пишет плату): энергия = длина цепей (HPWL, без GND) + штраф за смещение от позиции V1 и за поворот + штраф за пересечение и выход за контур. Закреплены ESP32, разъёмы, батарейный держатель, контрольные точки; вручную заданы дроссель L711 (70,9; 120,0; пады на 62,15 и 79,65 мм), J901 вплотную к левому краю (56,3; 62,0) и шунт R716 между клеммами J711 и J721 (Kelvin-метка NT712 едет с ним). Из пяти запусков (seed 1–4 легальны, длина цепей 2433–2465 мм) взят seed 4. Результат — стартовая точка, а не окончательное решение: перед трассировкой плату стоит просмотреть в KiCad; шёлк и подписи не причёсаны.

## Трассировка: состояние (03.10.2026)

**Все цепи соединены:** 1012 дорожек, 231 переходное отверстие; заливки GND на F.Cu/In1.Cu/B.Cu и +3V3 на In2.Cu, пять дополнительных полигонов входа и нагревателя. [Текущий вид F.Cu](review/Routing_top.png). Размещение и назначения выводов сохранены.

Завершены земля, +3V3, AUX_VIN, затворы LED, возврат LED1, питание помпы и измерительное ответвление LED2_OUT. LED2_OVP переложена для доступа к R727. Возврат LED1 приходит на силовой вывод шунта R716, а не на Kelvin net-tie. Отвод к F521 выполнен шириной 1 мм на внешнем слое (расчётный запас помпы 0,5 А); 0,25 мм к R727 — только измерительная ветвь OVP, не питание светильников. Основные силовые пути этими ответвлениями не заменены.

**Проверки:** KiCad 10.0.5: ERC 0; DRC 0 неподключённых цепей, 0 нарушений зазоров/замыканий, 0 замечаний по шелкографии (после `fix_silk.py`; до него было 120: 57 пересечений, 48 над открытой медью, 15 у края). 170 компонентов и 445 электрических выводов соответствуют схеме (`tools/check_sync.py`); размещение без пересечений. `hardware/check_all.py` проходит для основной PCB_V1; эта проверка сама по себе не проверяет cheap-version.

**Исправление инструментов:** `route_power.py`, `route_signals.py`, `route_complete.py` загружают соответствующий `.kicad_pro` вместе с платой. Без него заливка через Python игнорировала зазоры классов: вместо 0,4–0,5 мм применялось 0,2 мм. Доводчик теперь учитывает зазоры обеих цепей, не снимает препятствия возле конечных площадок и не подставляет 0,25 мм для неизвестного силового соединения. Силовые и переключающие цепи пропускает для ручной работы; исключения — только указанные одиночные ответвления F521 и R727. Последующая проверка CLI DRC обязательна.

**Усиление входа и PTC:** между J901 и F902 добавлена медь на F.Cu/B.Cu; +24V_LOADS от F902 к J601 перенесена с In2 на B.Cu. Сток Q601 связан с J601 полигонами на обоих внешних слоях. Площадки силовых THT подключены без терморазгрузки, возле истока Q601 добавлены четыре переходных отверстия Ø0,8/0,4 мм. Ответвление помпы переложено в обход полигона стока. Q601 остаётся вертикальным; размещение, схема и назначения выводов не менялись.

`tools/reinforce_input.py <board> --write` повторяемо обновляет только этот этап, сохраняя остальную трассировку. После него запускать `tools/verify_input_copper.py <board>` и CLI DRC. Проверка использует **фактически залитые** полигоны и контролирует непрерывные участки: вход — минимум 5,95 мм на каждом внешнем слое, питание нагревателя — 5,39 мм на B.Cu, путь стока — 1,75 мм на каждом внешнем слое. Это геометрическая проверка выбранных участков, а не тепловая квалификация всей платы: контактные сужения, металлизация отверстий и распределение тока между слоями требуют итоговой проверки. Остальные силовые цепи описаны ниже.

**Усиление +24V к LED и узлов каналов (04.10.2026):** кольцо +24V на In2 0,5 oz (95 мм, 2 мм) от F902 к F711/F721 и участок LED2_OUT на In2 (0,8 мм, 43 мм) убраны; вместо них внешние слои:

| Участок | Медь | Непрерывная ширина |
|---|---|---|
| +24V через полосу +24V_LOADS | входной полигон F.Cu продолжен под вершину полосы (кромка полосы: y = 157 − x), 10 переходных Ø0,8/0,4 вдоль неё | 7,2 мм до переходных |
| магистраль к CH1 и CH2 | B.Cu, полигон x 71–81,6, y 80–110 | 3,6 мм на самом узком месте |
| ветка к CH2 | B.Cu, полоса y 100–105,6 до F721 | 2,6 мм |
| питание F711 (CH1) | F.Cu, полигон 25×6 мм вместо полосы 2 мм, 12 переходных | 5,2 мм |
| питание F721 (CH2) | F.Cu, полигон + 6 переходных | 4,6 мм |
| LED1_VIN / LED2_VIN | F.Cu, полигоны вместо дорожек 2 мм | 2,2–2,9 мм |
| LED1_SW / LED2_SW | F.Cu, полигоны вместо дорожек 1,5 мм | 4,0–5,0 мм |
| LED2_OUT | B.Cu, 1,2 мм вместо In2 0,8 мм (около 45 мм) | 1,09 мм |

Оценка по IPC-2221 (1 oz, внешний слой): магистраль 3,6 мм при максимуме расчёта (CH1 на 80 Вт 4,61 А + CH2 1,29 А = 5,9 А) даёт около +9 К, полигоны LED1_VIN шириной 2,2 мм при 4,6 А около +12 К на коротком участке. Не менялись: LED1_OUT (0,8 мм на F.Cu, достаточно для 1,67 А), истоки Q711/Q721 (1,5 мм), возвраты, шина +12V.

`tools/reinforce_led.py <board> --write` повторяемо перестраивает только этот этап (зоны `auto:led-stage:*`, нужные дорожки и переходные; ставить после `reinforce_input.py`). `tools/verify_led_copper.py <board.json>` (JSON из `export_view.py`; Python с numpy, scipy и Pillow) считает по залитой меди ширину самого широкого непрерывного пути между точками и число переходных; `tools/freespace.py` — вспомогательный поиск свободных коридоров при проектировании. Результат: `verify_led_copper.py` PASS, DRC (с `.kicad_dru`) 0 ошибок и 0 неподключённых.

**Шина +12V, шелкография, драйвер (04.10.2026):**

- `tools/reinforce_12v.py`: линия вентиляторов (0,68 А) шла по In2 шириной 0,5 мм около 45 мм (около +28 К по IPC-2221); сегменты вне тесного места расширены до 0,8 мм (около +11 К), 6,5-мм перемычка между двумя переходными и дорожкой ESP_IO0 остаётся 0,5 мм (рядом на внешних слоях места нет). Шире B.Cu не получается: коридоры 0,3–0,7 мм.
- `tools/swap_heater_driver.py`: U601 = UCC27524ADR (ENA на +12V короткой перемычкой к рядом идущей дорожке, ENB на GND), значение и MPN у R716 и U601 на плате; схема и плата сверены по всем выводам (расхождений нет), ERC 0.
- `tools/fix_silk.py` (+ `silk_model.py`): удалены 29 линий шелка, которые пересекали площадки или контур платы (корпуса J301, J302, J601, J521 за краем, оси L711 через площадки, перекрытие контуров C901/D901); **все 170 обозначений теперь на шёлке** (168 на F.Silkscreen, 2 на B.Silkscreen — C911 и держатель батарейки), 1,0 мм высотой и штрихом 0,2 мм. До 04.10 только 67 лежали на шёлке, а 103 — на слое F.Fab/B.Fab с высотой 0,8 мм: в KiCad они «видны», но в Gerber шёлка их нет. Проверка геометрическая, штрих против штриха, как в DRC (`silk_model.py`): зазор до шелка 0,18 мм, до площадки 0,17 мм, до отверстий и переходных 0,2 мм, до края 0,45 мм. Медиана расстояния обозначения от выводов своей детали 0,6 мм; в плотных местах 39 обозначений стоят дальше 2 мм (до 10 мм: NT721, TP301, R905, C304, R403, NT712, R307, C103, D303, R410) — там обозначение читается по соседству, а не вплотную. Повторный запуск ничего не меняет. Вид сверху: [review/Board_top_cheap1.png](review/Board_top_cheap1.png).

**Петли DC/DC, пути возврата, производство (04.10.2026, ветка `cheap-fab`):**

- **ST1S14.** Цепь AUX_VIN от входных конденсаторов C905/C906 до вывода VIN 7 была около 20 мм с двумя переходными, половина на B.Cu над потолком +3V3, а не над землёй: оценка петли 13 нГн (`tools/analyze_dcdc_loops.py`, формулы микрополоски над плоскостью и переходного, порядок величины, не моделирование). Добавлен **C911** (100 нФ 0603 со склада, снизу под выводами 6/7, переходное на землю рядом, второе AUX_VIN-переходное у вывода 7; `tools/add_c911.py`): петля 4,8 нГн, выброс на VIN при токе 3,7 А за 5 нс оценивается в 3,5 В над 25 В. Остальные петли в норме: ST1S10 4,4 нГн (C101 в 6,5 мм), boost CH1 и CH2 — диод → выходные конденсаторы 3,7 и 3,8 нГн, SW-узел 1,2 и 1,3 нГн, исток → шунт 1,3 и 0,9 нГн; вся коммутационная петля boost 15–16 нГн (в ней 7 нГн — возврат по In1 от C716/C726 к шунтам R715/R725, 22–24 мм), выброс на SW около 6,5 В (CH1) и 3 В (CH2) при 100-вольтовых ключах и диодах. Устойчивость контуров ST1S14/ST1S10 расчётом не проверена (внутренняя компенсация, модели нет): [review/Bench_checklist_cheap1.md](review/Bench_checklist_cheap1.md).
- **Земля и пути возврата** (`tools/check_return_paths.py`, по заливке): In1 — один кусок меди, 92 % платы, без островов; пустоты больше 8 мм² — зона антенны ESP32 (48 × 6 мм, так задумано), антиконтактные отверстия THT и две «щели» от массивов переходных (8 × 3 мм у питания F711, 6 × 5 мм у перехода +24V; в них нет сигнальных цепей). Самое узкое место земли от входной клеммы J901.1 до силовых каскадов: 7,9–8,5 мм для LED-шунтов и возвратов, 7,2 мм для истока нагревателя, 5,9 мм для U902, 5,5 мм для ESP32 (нужно ≥ 5 мм; 12 А по 8 мм 0,5 oz даёт около 8 мОм, плюс заливки F.Cu и B.Cu). Переключающие цепи над пустотой In1: AUX_VIN 2,2 мм (у переходных рядом с U902), остальные не дольше 3 мм; сигнальные переходные на B.Cu без земляного рядом (11 штук: медленные SD_CS, RTC_VBAT, FAN_TACH, затвор LED1 через 3,4 мм на B.Cu) — информация, не отказ.
- **Производство** — [FAB.md](FAB.md): Gerber и сверловка 12 файлов (`tools/export_fab_cheap.py`), `check_fab.py` 0 FAIL / 2 WARN (как у PCB_V1), исправления по нему (`tools/fab_touchups.py`, `fix_silk.py`). Всё одной командой — `tools/run_checks.py` (9 шагов, около 7 минут): 9 из 9. Загрузка в JLCDFM остаётся за вами.
- **Для оператора сборки** — [assembly/Assembly_cheap1.pdf](assembly/Assembly_cheap1.pdf), 34 страницы A4 на русском: правила, страница «Главное о полярности», 10 шагов сборки (общий план платы с отмеченными деталями, таблица деталей по номиналам с корпусом, MPN и источником), 16 «плоскостей» A1–D4 (по 25 × 25 мм, у каждой детали позиция и номинал, красные метки полярности и вывода 1), карточки полярности и ориентации по типам деталей, контроль после сборки. Не ставятся: контрольные точки TP, пары NT и C106 (DNP). Пересборка после изменения платы: `tools/export_assembly.py` (KiCad Python) → `tools/make_assembly_doc.py` (Python с Pillow и PyMuPDF, шрифт Arial из Windows).
- **Короткий лист для оператора** — [assembly/Assembly_cheap1_A4.pdf](assembly/Assembly_cheap1_A4.pdf), 4 страницы A4: SMD-детали (142 шт.) и выводные (17 шт.) отдельно, у каждой группы своя таблица «позиции — номинал — корпус — MPN — полярность — шаг — зона» (все позиции сразу, одна строка на тип детали) и одна большая схема установки во всю страницу (все позиции, красные метки полярности, сетка зон A–D × 1–4, внизу вид снизу с C911 или BT301; на схеме SMD неполярные детали зелёные, полярные оранжевые, номинал рядом с позицией там, где хватило места — у 110 из 141). Пересборка: `tools/export_assembly.py` → `tools/make_assembly_sheet.py assembly.json assembly/Assembly_cheap1_A4.pdf` (тот же дамп платы и тот же BOM, что у длинной инструкции). Схема SMD (страница 1) есть и отдельным листом **A3** — [assembly/Assembly_cheap1_SMD_A3.pdf](assembly/Assembly_cheap1_SMD_A3.pdf): та же картинка в 1,4 раза крупнее, номинал рядом с позицией у 140 из 141 деталей (на A4 — у 110); собирается тем же скриптом с ключом `--a3 assembly/Assembly_cheap1_SMD_A3.pdf`.

**Оставшиеся проверки и ограничения:**

- На собранном прототипе: устойчивость обоих DC/DC (ST1S14 с электролитом 820 мкФ и ST1S10 с 4,7 мкГн) и нагрев — на макете по [чек-листу](review/Bench_checklist_cheap1.md). Силовые таблицы `POURS`/`TRACKS` в `tools/route_power.py` пока пусты; полигоны заданы в `tools/reinforce_input.py` и `tools/reinforce_led.py`. Запуск начальной стадии `route_power.py` удаляет всю текущую трассировку — использовать только на рабочей копии при подготовке нового силового прогона.
- Итоговые ориентиры нагрузок: общий вход до 11,9 А, +24V_LOADS 5,8 А, HEATER_DRAIN 5,3 А; нулевое число разрывов и геометрическая ширина не подтверждают допустимый ток и нагрев.
- Загрузить архив в JLCDFM ([FAB.md](FAB.md), раздел 5), пересобрать корпус под потолок около 40 мм. Основной проект PCB_V1 этим изменением не затронут.

Для повторной доводки текущего результата: `route_complete.py <board>` (без `--write` — проверочный проход); заполнение зон — `route_power.py <board> --finish --write`. Рядом с рабочей копией платы нужны одноимённые `.kicad_pro` и `.kicad_dru`. Просмотр меди: `tools/export_view.py` + `tools/view.py`.

## BOM и закупка

Для [импорта в LCSC](https://www.lcsc.com/bom) используйте [BOM_LCSC_cheap1.csv](BOM_LCSC_cheap1.csv). В нём 37 позиций для **одной платы с учётом склада**, 868 деталей с округлением до минимальных партий из снимка цен. Строка 1 — заголовки, данные начинаются со строки 2; при импорте сопоставьте `Quantity` с количеством и `LCSC Part Number` с кодом LCSC. Множитель количества — 1. Батарейка CR2032 без кода LCSC исключена и приобретается отдельно. Текущие цены, наличие и кратность магазин уточнит при импорте. CSV обновляется вместе с BOM командой `python hardware/cheap-version/tools/export_bom.py`.

`tools/export_bom.py` по схеме и складу пишет [BOM_cheap1.csv](BOM_cheap1.csv) (72 строки, 160 деталей; без net-tie, контрольных точек и C106 DNP; плюс CR2032; сам предохранитель 10 А для F902 не закупается, у пользователя есть, закупается только держатель) и [BUY_cheap1.csv](BUY_cheap1.csv) (что докупить). Со склада идут 94 детали, докупается 66 деталей в 38 строках. Оценка заказа LCSC с минимальными партиями: **$33,86**, без CR2032, доставки и налогов. Для пяти позиций цены и наличие сверены 04.10.2026; остальные цены — снимок PCB_V1 от 28–30.09.2026, их наличие повторно не проверялось. Дата и ссылка указаны в колонке Note. Цены соседних номиналов больше не используются.

## Экспериментальный FDM-трафарет

Для пробной ручной пайки сделаны [полный STL 100×100 мм](stencil/cheap_full.stl), [полный 3MF](stencil/cheap_full_geometry.3mf) и [тестовый купон 40×40 мм](stencil/cheap_test.stl) под Bambu Lab A1 mini с соплом 0,4 мм и PLA. Купон охватывает плотную область платы около U601 и мелких пассивных компонентов; его лучше напечатать первым. Для прямого открытия в Bambu Studio есть также [3MF купона](stencil/cheap_test_geometry.3mf). Превью: [cheap_test_preview.png](stencil/cheap_test_preview.png).

Для сопла **0,2 мм** добавлен предпочтительный вариант: [тестовый 3MF](stencil/cheap_test_02_geometry.3mf), [полный 3MF](stencil/cheap_full_02_geometry.3mf), а также соответствующие [STL купона](stencil/cheap_test_02.stl) и [полной платы](stencil/cheap_full_02.stl). В нём отверстия расширены только на 0,03 мм; толщина остаётся 0,20 мм (два слоя по 0,10 мм). Файлы без суффикса `_02` оставлены как более грубый запасной вариант для сопла 0,4 мм.

Это однослойный трафарет толщиной 0,20 мм. Отверстия взяты из `F.Paste`, для FDM они расширены на 0,08 мм (вариант 0,4 мм) или на 0,03 мм (вариант 0,2 мм) и упрощены до прямоугольных контуров. Поэтому это проверка идеи, а не замена лазерному трафарету: сначала нужно проверить купон и количество нанесённой пасты. Для `_02` задать сопло 0,2 мм, слой 0,10 мм, первый слой 0,10 мм, ширину линии около 0,22–0,24 мм, без поддержек и разглаживания, с плоской ориентацией и бримом; перед печатью проверить слайс в Bambu Studio. Для старого варианта 0,4 мм оставить слой и первый слой 0,20 мм. Малые перемычки между соседними площадками всё равно нужно проверить на превью.

SCAD и генератор лежат в [stencil/](stencil/) и [tools/make_stencil.py](tools/make_stencil.py). Повторная генерация:

```text
python tools/make_stencil.py --scad stencil/cheap_full.scad --test-scad stencil/cheap_test.scad --expand 0.08 --thickness 0.20
openscad -o stencil/cheap_full.stl --export-format binstl stencil/cheap_full.scad
openscad -o stencil/cheap_test.stl --export-format binstl stencil/cheap_test.scad
```

Для варианта с соплом 0,2 мм:

```text
python tools/make_stencil.py --scad stencil/cheap_full_02.scad --test-scad stencil/cheap_test_02.scad --expand 0.03 --thickness 0.20
openscad -o stencil/cheap_full_02.stl --export-format binstl stencil/cheap_full_02.scad
openscad -o stencil/cheap_test_02.stl --export-format binstl stencil/cheap_test_02.scad
```

Для стенда добавлен трафарет с полем **15 мм по всем четырём сторонам**: [3MF 130,05×130,05 мм](stencil/cheap_full_02_margin15_geometry.3mf), [STL](stencil/cheap_full_02_margin15.stl) и [SCAD](stencil/cheap_full_02_margin15.scad). Поля оставлены пустыми для прижима рамкой; рабочее окно остаётся 100,05×100,05 мм. Генерация:

```text
python tools/make_stencil.py --scad stencil/cheap_full_02_margin15.scad --expand 0.03 --thickness 0.20 --margin 15
openscad -o stencil/cheap_full_02_margin15.stl --export-format binstl stencil/cheap_full_02_margin15.scad
openscad -o stencil/cheap_full_02_margin15_geometry.3mf --export-format 3mf stencil/cheap_full_02_margin15.scad
```

Если понадобятся поля только слева и справа, генератор поддерживает раздельные размеры: используйте `--margin-x 15 --margin-y 0`.

### Стенд для нанесения пасты

Сделан параметрический двухдетальный стенд: нижняя ванночка и шарнирная прижимная рамка. Нижняя деталь имеет наружный размер около 146×151 мм с учётом шарнира, карман под плату 100,65×100,65 мм и рельеф под нижний держатель CR2032 BT301. Рамка имеет окно 101×101 мм, два отверстия под передние винты M3 и шарнир под штифт Ø3 мм. Шарнир состоит из двух внешних петель основания и центральной петли рамки; осевой зазор между ними уменьшен до 1 мм, чтобы рамка не уезжала вдоль штифта. Ухо рамки одно, по центру задней кромки, ровно под своим коленом (36 мм, x −18…18); отверстие Ø3,5 мм под штифт вычитается из готового тела и свободно во всех трёх коленах (раньше ухо было сдвинуто на 18 мм и закрывало 29 % отверстия). **Петля печатается без поддержек:** ось штифта поднята на 1,85 мм (z = 8,45 мм), так что низ трубки лежит в одной плоскости с низом рамки и рамка ложится на стол целиком (раньше трубка торчала на 1,85 мм ниже кольца, на столе оказывалась одна трубка, а под кольцом было 8 792 мм² нависаний; теперь нависаний 70 мм² — нижняя дуга трубки, как у любого горизонтального цилиндра Ø7 мм); ухо основания — блок до оси на всю ширину колена, ухо рамки заканчивается на 0,8 мм за осью (иначе его угол врезается в кромку основания при открытии), отверстие под штифт — капля остриём вверх. Рамка открывается на 3…170° без пересечения с основанием (проверено в OpenSCAD по 8 углам). В первой версии поля трафарета сделаны по 15 мм со всех сторон, чтобы ракель начинал и заканчивал ход за пределами платы.

Файлы для печати: [нижняя часть 3MF](stencil/stencil_jig_base_geometry.3mf), [рамка 3MF](stencil/stencil_jig_frame_geometry.3mf), [нижняя часть STL](stencil/stencil_jig_base.stl), [рамка STL](stencil/stencil_jig_frame.stl) и [параметрический SCAD](stencil/stencil_jig.scad). Превью сборки: [stencil_jig_preview.png](stencil/stencil_jig_preview.png). **Пробная петля** (три колена по 12 мм и небольшие площадки, те же высоты и зазоры): [нижняя часть](stencil/stencil_jig_hinge_test_base.stl) и [верхняя часть](stencil/stencil_jig_hinge_test_frame.stl) — печатаются плашмя без поддержек примерно за 10 минут; в них проверяются посадка штифта Ø3 мм и ход петли до печати всего стенда. Экспорт отдельных деталей из OpenSCAD:

```text
openscad -o stencil/stencil_jig_base.stl --export-format binstl stencil/stencil_jig_base.scad
openscad -o stencil/stencil_jig_frame.stl --export-format binstl stencil/stencil_jig_frame.scad
openscad -o stencil/stencil_jig_hinge_test_base.stl --export-format binstl stencil/stencil_jig_hinge_test_base.scad
openscad -o stencil/stencil_jig_hinge_test_frame.stl --export-format binstl stencil/stencil_jig_hinge_test_frame.scad
```

Для первой печати стенда достаточно PLA, слоя 0,20 мм, 4 стенок, 25–35% заполнения, без поддержек и с бримом вокруг шарнирных ушек. В рамку можно наклеить тонкую полоску TPU, силикона или каптона: она компенсирует неровность PLA и не даёт пережать трафарет. В нижние карманы устанавливаются два M3-гайки; шарнир лучше собрать на гладком винте или прутке Ø3 мм. Перед серийной печатью нужно проверить посадку реальной платы: зазоры и положение рельефа BT301 вынесены параметрами в начало `stencil_jig.scad`.

| Ref | Артикул | LCSC | Проверенная позиция |
| --- | --- | --- | --- |
| R102 | 0603WAF3162T5E | [C25967](https://www.lcsc.com/product-detail/C25967.html) | 31,6 кОм, 1%, 0603 |
| R907 | 0603WAF4703T5E | [C23178](https://www.lcsc.com/product-detail/C23178.html) | 470 кОм, 1%, 0603 |
| R904 | RT0603BRD0788K7L | [C728599](https://www.lcsc.com/product-detail/C728599.html) | 88,7 кОм, 0,1%, 0603 |
| R716 | JER2512F3R120 (JIERR) | [C49164917](https://www.lcsc.com/product-detail/C49164917.html) | 0,12 Ом, 1%, 3 Вт, 50 ppm/K, 2512 |
| L101 | FXL0630-4R7-M | [C167220](https://www.lcsc.com/product-detail/C167220.html) | 4,7 мкГн |

**Держатель F902** — XFCN XF-508P-B-B, [C19727305](https://www.lcsc.com/product-detail/C19727305.html) (по странице LCSC на 04.10.2026 в наличии 45 625 шт., от $0,26). На [странице JLCPCB](https://jlcpcb.com/partdetail/C19727305) он числится как деталь только для монтажа PCBA, отдельно не продаётся: поэтому инструмент JLCPCB для заказа деталей показывает по нему «No matches found». Покупать держатель в LCSC (импорт `BOM_LCSC_cheap1.csv` его находит). Предохранитель 10 А (MINI, 0297010.WXNV) из закупки убран. Третья «не найденная» строка в том же инструменте (`Description / CUSTOMER PART NUMBER`) — это заголовок CSV, прочитанный как деталь; игнорировать.

R716 заменяет предположительный FRM252WFR120TM. По [даташиту JIERR](https://datasheet.lcsc.com/datasheet/pdf/02ae4b20613551dea68a63964573e262.pdf) корпус 6,4×3,2×0,8 мм, короткие торцевые электроды 0,9 мм (версия без L): они перекрывают существующие площадки 2512. Геометрия платы сохранена. Рассеяние около 0,33 Вт при 1,667 А; паспортные 3 Вт требуют соблюдения условий охлаждения и снижения мощности выше 70 °C. Номинал и допуск не изменены, ток CH1 остаётся прежним.

Склада хватает, но без запаса остаются: 10 мкФ 50 В (6 шт из id 47; ещё 2 шт id 44 без MPN), 470 мкФ 63 В, 820 мкФ 25 В, DTMSS-27, IRL2505 и обе BSC146N10LS5 — при ошибке монтажа их придётся докупать (электролиты EEEFT1E821AP и EEVFK1J471M на LCSC есть: C178593, C178728).

## DTMSS-27 на плате (вариант A)

Версия -V по даташиту Feryster (допуски ±10 %): тороид стоит на ребре, два провода Ø1,9 мм вниз с шагом 17,5 мм, выводы 20±5 мм (после установки подрезать), корпус 32,5 мм (диаметр) × 16 мм (ширина), окно 5 мм, зазор до платы не более 2 мм. Футпринт: отверстия Ø2,4 мм с КП Ø4,2 мм на (±8,75; 0) мм, габарит 16×32,5 мм, куртярд 22,2×36,2 мм; ось тороида вдоль линии выводов. **Высота над платой около 35 мм (до 38 мм)**: потолок корпуса `Z_CEIL` из `../enclosure/` придётся поднять с 21 до примерно 40 мм; на размещении дроссель ставить у края платы, не над мелкими деталями.

## План

1. Проверка схемы в KiCad (открыть `cheap-version.kicad_pro`).
2. ~~BOM cheap-1 и закупка~~ — готово, см. выше.
3. ~~Новая плата из схемы и размещение~~ — готово; **трассировка** — все цепи соединены, силовая медь усилена (вход, PTC, +24V к LED, узлы каналов); шина +12V, геометрические проверки DC/DC и шелкография завершены. Внешний JLCDFM и испытания прототипа остаются.
4. ~~Gerber и заказной BOM~~ — готово ([FAB.md](FAB.md)); пересчёт корпуса из `../enclosure/` под высоту и новые разъёмы — отдельно.

Вход J901 развёрнут входами проводов к левому краю. Проектное посадочное место
`TerminalBlock_KF301_1x02_P5.00mm_Horizontal_Input` имеет обратную нумерацию
относительно библиотечного MKDS: вывод 1 GND снизу (56,3; 62), вывод 2 +24V
сверху (56,3; 57). Отверстия и полярность сохранены. Корпус MKDS остаётся
приближённой 3D-моделью KF301.

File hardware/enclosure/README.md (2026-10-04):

# Корпус GrowBox для PCB_V1

Печатный корпус из двух деталей — **основание** и **крышка** — для платы 100×100 мм (ревизия 0.22). Крепление на стену ушками, вентиляция, FDM из PLA, крышка держится на защёлках без винтов. Модель параметрическая (CadQuery), построена по STEP-экспорту платы и проверена на пересечения с ним. **Не печаталась:** допуски защёлок и размеры вилок ответных разъёмов нужно проверить на первом отпечатке.

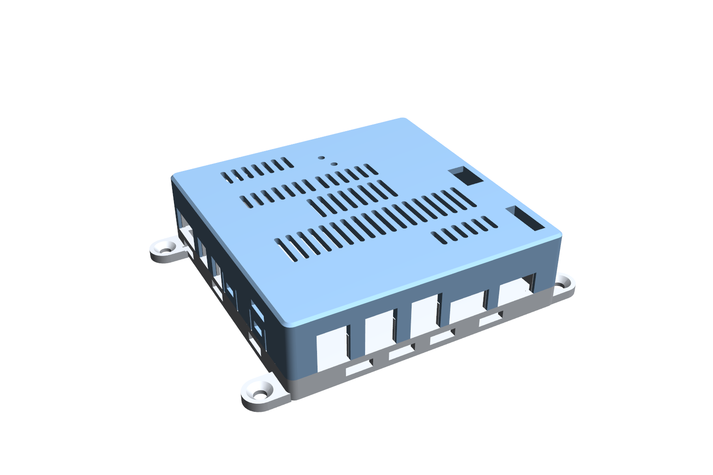
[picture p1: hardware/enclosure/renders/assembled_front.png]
Корпус, вид со стороны клемм


## Файлы

| Файл | Что это |
|---|---|
| `GrowBox_base.step`, `GrowBox_lid.step` | Детали в системе координат STEP платы (X = x KiCad, Y = −y KiCad, низ платы Z = 0): их можно загрузить вместе с `kicad-cli pcb export step` и посмотреть сборку |
| `GrowBox_base_print.stl`, `GrowBox_lid_print.stl` | Для печати, уже в печатной ориентации: основание — полом на стол, крышка — потолком на стол. Поддержки не нужны |
| `GrowBox_*_coupon_print.stl` | Фрагмент стенки 14 мм с защёлкой, основание и крышка. Печатать **первым** (около получаса) и проверить посадку |
| `enclosure.py` | Генератор. Все размеры и места вырезов — константы в начале файла |
| `check_enclosure.py` | Проверка по STEP платы: пересечения и зазоры |
| `render_enclosure.py` | Картинки в `renders/` |

## Конструкция

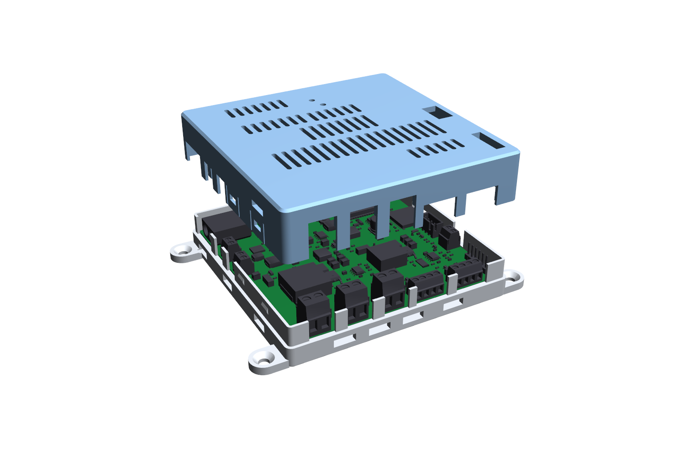
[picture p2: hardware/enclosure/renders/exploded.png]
Разнесённый вид


- Габарит 106×106×31,2 мм, с ушами 132 мм. Стенки 2,6 мм (кратно соплу 0,4 мм). Внутри 100,8×100,8: зазор до края платы 0,4 мм.
- Плата **лежит** на опорах (8 блоков 8×2 мм под рёбрами крышки и 4 угловых, верх опор на уровне низа платы) и прижимается сверху 8 рёбрами крышки на свободных участках края. Отверстий в плате не нужно. Опоры стоят только в местах, где снизу у края ничего нет; снизу плата занята лишь держателем BT301.
- От пола до платы 5,2 мм (низ BT301 −4,19 мм, зазор 1,01 мм), от платы до потолка 19,4 мм. Самая высокая деталь F902 (18,75 мм от низа платы) — зазор до потолка **2,25 мм**; высота F902 не измерена, см. «Что проверить».
- Стык «паз–шип»: на основании шип 1,2 мм (поднимается на 9 мм над плоскостью стыка z = 1,6 мм, то есть над верхом платы), на крышке внешняя юбка 1,2 мм, зазор 0,2 мм. Стык лежит на уровне верха платы, поэтому вырезы под разъёмы открыты в юбке и шипе сверху вниз, без перемычек.
- Защёлки: 7 окон 6 мм в юбке крышки (по трём сторонам) против гребней 0,6 мм на шипе основания. Юбка вокруг окна отделена щелями 0,8 мм и работает как гибкий палец (прогиб 0,4 мм, расчётная деформация около 0,7 %). Гребень скошен под 27° со стороны надевания крышки и под 23° со стороны снятия.
- Снять крышку: плоская отвёртка в прорезь у нижней кромки крышки (две: на верхней стороне, x = 82, и на правой, у верхнего угла, y = 62), затем приподнять по очереди каждую сторону.
- Стенное крепление: 4 уха, отверстие Ø4,5 мм с конусом под головку Ø8,6 мм; межосевое расстояние 120×92 мм. Крепёж в комплект не входит. Металла рядом с антенной ESP32 нет.

### Отверстия

Сторона и координаты даны по виду платы в KiCad (верх — край антенны ESP32, низ — клеммы светодиодов и вентиляторов).

| Где | Что | Окно |
|---|---|---|
| Слева | J901 XT60 (вилка ответного разъёма) | y 52,6…70,2, до z 11,2 |
| Слева | J601 PTC, J521 помпа | y 75,3…83,8 и 89,3…97,8, до z 10,8 |
| Снизу | J711, J721, J731 светодиоды (KANGNEX 5,08) | x 57,0…68,7, 74,0…85,7, 91,0…102,7, до z 16,3 |
| Снизу | J501, J511 вентиляторы | x 106,3…121,8 и 126,3…141,8, до z 10,8 |
| Справа | J401 microSD (карту вставлять и вынимать) | y 79,9…95,7, до z 4,65 |
| Справа | J302 поплавок | y 114,2…122,7, до z 10,8 |
| Потолок | J301 датчик SHT4x (XH, вилка сверху) | x 141,8…149,3, y 96,4…110,1 |
| Потолок | J201 UART (штыревая 1×6, Dupont сверху) | x 144,2…148,8, y 129,8…146,9 |
| Потолок | SW201 RESET, SW202 BOOT | трубки Ø6,4/Ø2,8, низ трубки z 4,5 (колпачок 3,1) — нажимать скрепкой или зубочисткой |

Вентиляция: щели в потолке над горячими узлами (вход питания и F902, Q601/U601, U902/L902/D902, U101/L101, драйверы светодиодов, Q501/Q511), горизонтальные щели в стенках крышки и щели в стенках основания под платой. Пол сплошной: он прижат к стене.

Клеммы затягиваются при снятой крышке; провода уходят в открытые вырезы.

## Печать

- Сопло 0,4, слой 0,2, 3 периметра, 4 верхних/нижних слоя, заполнение 20–25 %, без поддержек. Масса обеих деталей около 50–60 г (объём 38,5 + 39,8 см³ при сплошной модели).
- Мосты: щели в стенках 10 мм и окна защёлок 6 мм. Нужен обдув; при провисании уменьшить `BASE_SLOT_L` / `LID_SLOT_L`.
- **PLA размягчается около 55–60 °C.** Греющиеся ключи, диоды и дроссели пластика не касаются (до потолка не меньше 9 мм), но под нагрузкой проверьте температуру крышки и стенок на прототипе (цель из DESIGN: подъём SS5P10 ниже 50 °C). Если они нагреваются выше ~50 °C, печатайте из **PETG**: геометрия от материала не зависит.

## Проверка

`python check_enclosure.py` (в окружении с CadQuery; STEP платы выгружается через `kicad-cli`, путь к нему — `KICAD_CLI`) на ревизии 0.22:

- основание и крышка не пересекаются;
- ни одна деталь платы не пересекается с корпусом; 256 деталей из 295 заведомо дальше 2,5 мм от оболочки, остальные 39 проверены точно: **минимальный зазор 0,65 мм** (экран ESP32 до стенки), клеммы KANGNEX 0,8 мм, microSD 0,73 мм, кнопки до трубок 1,45 мм, F902 до потолка 2,25 мм;
- сама плата касается опор и низа рёбер по построению.

Ключевые сечения: [через защёлку](renders/section_snap.png), [через клемму](renders/section_front.png). Остальные виды: [без крышки](renders/open_top.png), [крышка изнутри](renders/lid_inside.png), [сзади](renders/assembled_back.png).

## Что проверить на первом отпечатке

1. Печать фрагментов-купонов: посадка шипа и гибкость пальца (нужны ли поправки `JOINT_GAP`, `RIDGE_P`, `SNAP_WIN`).
2. Высота F902 со вставкой: сейчас потолок 21,0 мм (`Z_CEIL`) при расчётной высоте 18,75 мм. После измерения проверить зазор и при необходимости изменить `Z_CEIL`.
3. Вилки ответных разъёмов (XT60, XH, Dupont) и провода в вырезах; 3D-модели разъёмов упрощены.
4. Крепёж (винты и дюбели) и фактическое направление монтажа.

## Пересборка

```sh
python -m pip install cadquery==2.8.0 vtk
python hardware/enclosure/enclosure.py
python hardware/enclosure/check_enclosure.py            # с --fast быстрее, без списка зазоров
kicad-cli pcb export step --force --no-dnp -o board.step hardware/PCB_V1/PCB_V1.kicad_pcb
python hardware/enclosure/render_enclosure.py board.step
```

При изменении расстановки платы пересоберите корпус и повторите проверку: окна и опоры привязаны к координатам разъёмов и свободным участкам края.

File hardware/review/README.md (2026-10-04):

# Review artifacts

Current revision **v22** (PCB_V1 0.22). Electrical, cost and assembly reports are produced by the check scripts from the `hardware` directory; do not edit generated reports by hand. Placement images are exported directly from KiCad; the final check log is captured from `check_all.py`.

| File | Content |
|---|---|
| `ERC_v22.rpt` | KiCad ERC report (0 errors / 0 warnings) |
| `DRC_placement_v22.rpt` | KiCad DRC of the placed, unrouted board before routing (0 violations; 341 unconnected links) |
| `DRC_routed_v22.rpt` | KiCad DRC of the routed board (0 violations, 0 unconnected pads); written by `check_all.py --write` |
| `LED_power_v22.txt` | `analyze_led_power.py` — LED boost sizing, 72 cases per channel |
| `Power_path_v22.txt` | `analyze_power_path.py` — input, fuses, TVS margins, 12 V buck, switches |
| `Copper_v22.txt` | `analyze_copper.py` — conductor widths, via counts and drops for the confirmed stack (1.6 mm, 1 oz outer, 0.5 oz inner) |
| `JLC_assembly_v22.txt` | `estimate_jlc_assembly.py` — JLCPCB PCB + assembly for 2 and 5 boards (fees, JLC part prices, joints, stock) |
| `BOM_cost_v22.txt` | `audit_bom_cost.py` — every schematic reference priced from `PCB_V1/price_snapshot_v22.json` (1 and 5 boards, MOQ, EUR) |
| `Checks_v22.txt` | Full `check_all.py` log for 0.22 |
| `Placement_v22_top.png` / `.svg`, `Placement_v22_bottom.png` / `.svg` | Placement exported from KiCad (top: F.Cu, F.Fab, F.Silkscreen, outline; bottom mirrored) |
| `Root_v22.png` … `LEDDrivers_v22.png` | Schematic sheets rendered from KiCad SVG export |
| `DFM_JLCPCB_v22.txt` | `check_fab.py` — the board against the published JLCPCB limits (0 FAIL, 2 WARN) |
| `Routed_v22_top.png`, `Routed_v22_bottom.png` | 3D renders (`kicad-cli pcb render`) of the routed board, top and bottom |
| `Routed_v22_F.png`, `Routed_v22_In1.png`, `Routed_v22_In2.png`, `Routed_v22_B.png` | Copper layers of the routed board (`kicad-cli pcb export svg`; B.Cu mirrored): GND pours red, white = clearance |

Only the current revision is kept here. When `REV` in `check_all.py` changes, delete the previous revision's files in the same commit. Reports of earlier revisions (v16–v21, and 0.1–0.15 under `history/`) are in git history; links are in the archive section of `../PCB_V1/CHANGELOG.md`.

The first routed layout of 0.22 (2026-10-01, `../PCB_V1/ROUTING.md`) adds `DRC_routed_v22.rpt`, the `Routed_v22_*` images and a `Checks_v22.txt` that includes `verify_routing.py`.

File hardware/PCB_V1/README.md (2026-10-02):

# PCB_V1 — контроллер GrowBox, ревизия 0.22

Открыть [PCB_V1.kicad_pro](PCB_V1.kicad_pro) в KiCad 10. После обновления репозитория перечитать открытый проект с диска перед сохранением.

**Состояние на 01.10.2026:** плата 100×100 мм полностью разведена; 170 компонентов, включая четыре net-tie. ERC — 0 ошибок и предупреждений, DRC — 0 нарушений и несоединённых связей. Gerber и заказной BOM готовы. Локальная DFM-проверка: 0 FAIL, два предупреждения; повторный JLCDFM и проверка механики ещё не подтверждены. Открытые вопросы — [DESIGN.md](DESIGN.md#открытые-вопросы).

## Основные параметры

- Вход **24 В**, XT60PW-M: 1 — GND, 2 — +24V; электронной защиты от переполюсовки нет.
- PTC 24 В / 100 Вт, помпа 24 В / около 6 Вт, два четырёхпроводных вентилятора 12 В.
- Свет: CH1 — панель 1,111 А; CH2 — две линейки параллельно, 0,465 А суммарно; общее управление яркостью. Возвраты разных каналов не объединять между собой или с GND.
- ESP32-WROOM-32E, PCF8563T + CR2032, microSD, внешний SHT4x и поплавок.
- Четыре слоя: 1 oz снаружи, 0,5 oz внутри; номинальная толщина 1,6 мм. Без крепёжных отверстий, разъёмы и microSD по краям, держатель батарейки снизу. Первые платы собираются вручную.

## Документация

| Задача | Документ |
|---|---|
| Понять схему, расчёты и нерешённые вопросы | [DESIGN.md](DESIGN.md) |
| Заказать детали | [BOM.md](BOM.md), [CSV для LCSC](BOM_LCSC_v22.csv), [XLSX](BOM_LCSC_v22.xlsx) |
| Заказать PCB | [FAB.md](FAB.md), [архив Gerber и сверловки](../fab/PCB_V1_v22_jlcpcb.zip) |
| Проверить механику, стек и 3D-модели | [PLACEMENT.md](PLACEMENT.md) |
| Напечатать корпус | [../enclosure/README.md](../enclosure/README.md) |
| Проверить трассировку | [ROUTING.md](ROUTING.md); расчётные ограничения — [ROUTING_PREP.md](ROUTING_PREP.md) |
| Проверить RTC и совместимость прошивки | [RTC_COMPATIBILITY.md](RTC_COMPATIBILITY.md) |
| Найти историю изменений | [CHANGELOG.md](CHANGELOG.md) |
| Запустить проверки | [../README.md](../README.md); сохранённые [отчёты](../review/) |

Справочные данные: [полный заказной BOM](BOM_PCB_V1_v22.csv), [состав схемы](BOM_schematic.csv), [карточки выбранных деталей](BOM_v0.1.md), снимки [цен LCSC](price_snapshot_v22.json) и [JLCPCB](jlc_snapshot_v22.json). Цены датированы 28–30.09.2026; стоимость компонентов и фактической корзины с минимальными партиями различается, см. [BOM.md](BOM.md).

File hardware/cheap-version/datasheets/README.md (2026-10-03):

# Даташиты cheap-1

PDF не хранятся в репозитории (`.gitignore`): положите файлы с этими именами сюда, чтобы скрипты и ссылки в `../README.md` работали.

| Файл | Деталь | Откуда |
|---|---|---|
| `ST1S10.pdf` | ST1S10 (3,3 В из 12 В) | ST, DocID13844 Rev 7, от пользователя |
| `Feryster_DTMSS-27.pdf` | дроссель DTMSS-27/0.047/15-V | Feryster, от пользователя |
| `IRS4426_IRS4427_IRS4428.pdf` | драйвер затвора нагревателя | Infineon/IR, DS 97481, от пользователя |
| `SBRT15U100SP5.pdf` | диоды LED-boost | Diodes Inc., DS36524 Rev. 9-2, от пользователя |
| `BSC146N10LS5.pdf` | ключи LED-boost | Infineon, Rev. 2.3, от пользователя |
| ST1S14 | 24→12 В | [st.com](https://www.st.com/resource/en/datasheet/st1s14.pdf) |

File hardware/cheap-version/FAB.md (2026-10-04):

# cheap-1 — файлы для производства на JLCPCB

04.10.2026. Плата `cheap-version.kicad_pcb` проверена и экспортирована в Gerber и сверловку; архив для загрузки — [fab/cheap-version_cheap1_jlcpcb.zip](fab/cheap-version_cheap1_jlcpcb.zip) (12 файлов, 498 КБ). Экспорт повторяем: `tools/export_fab_cheap.py --check` пересобирает архив и сравнивает с лежащим в репозитории. **Архив не загружался в JLCDFM и на jlcpcb.com** — это остаётся сделать вам (раздел 5).

## 1. Что в архиве

Gerber RS-274X (X2, формат 4.6, мм, расширения Protel) и Excellon, заголовки с датой и версией KiCad заменены константами, чтобы повторный экспорт давал тот же архив байт в байт. Состав тот же, что у PCB_V1 (см. [../PCB_V1/FAB.md](../PCB_V1/FAB.md)), префикс `cheap-version-`:

| Файл | Содержимое |
|---|---|
| `-F_Cu.gtl`, `-In1_Cu.g1`, `-In2_Cu.g2`, `-B_Cu.gbl` | четыре слоя меди (In1 — сплошная земля, In2 — сигналы и +3V3) |
| `-F_Mask.gts`, `-B_Mask.gbs` | паяльная маска, отверстия 1:1 с площадками, переходные закрыты |
| `-F_Silkscreen.gto`, `-B_Silkscreen.gbo` | шёлк: штрих 0,2 мм, текст 1,0 мм, не ближе 0,15 мм к площадкам, отверстиям и переходным; все 170 обозначений деталей напечатаны (168 сверху, 2 снизу) |
| `-F_Paste.gtp` | паста сверху (нижней пасты нет: единственная нижняя деталь C911 и держатель батарейки паяются вручную) |
| `-Edge_Cuts.gm1` | контур 100,000 × 100,000 мм |
| `-PTH.drl`, `-NPTH.drl` | сверловка: 284 металлизированных отверстия в 11 диаметрах (0,30 мм ×195 — переходные 0,3/0,65; 0,40 мм ×38; выводы 0,95–2,40 мм), 2 неметаллизированных Ø1,0 мм, пазов нет |

Экспорт читает свои файлы обратно и сверяет с платой: функции файлов, размер контура, самый узкий штрих меди (0,25 мм) и шёлка (0,2 мм), размеры и число отверстий.

## 2. Параметры заказа

Те же, что у PCB_V1: 4 слоя FR-4, 100 × 100 мм, 1,6 мм (стандартный стек JLC04161H-7628, импеданс не контролируется), медь 1 oz снаружи / 0,5 oz внутри, HASL (первые платы паяются вручную), маска и шёлк любого цвета, маска на переходных закрыта, минимальное отверстие 0,3 мм / 0,4 мм (наши 0,3/0,65 и 0,4/0,8 мм подходят без доплаты), 5 плат. Названия пунктов у JLCPCB меняются, сверьте по форме заказа.

## 3. Что проверено

`tools/run_checks.py` запускает всё сразу (9 шагов; для двух медных проверок нужен Python с numpy, scipy и Pillow в переменной `CHEAP_PY`). Отсутствие `CHEAP_PY` считается провалом, а не пропуском проверок. Результат на этой плате: **9 из 9**.

| Проверка | Итог |
|---|---|
| ERC | 0 нарушений |
| DRC с правилами проекта (`.kicad_dru`) | 0 нарушений и замечаний, 0 неподключённых цепей |
| Схема и плата по выводам (`check_sync.py`) | 445 выводов, 0 расхождений |
| Нормы JLCPCB (`../check_fab.py`) | **0 FAIL, 2 WARN** (те же два, что у PCB_V1: поясок переходных 0,175 мм при рекомендуемых 0,2 мм — стандартный заказ 0,3/0,4 мм выдерживается; 42 пары дорожек одной цепи ближе 0,25 мм без касания — узкие щели внутри одной цепи, замыкания нет) |
| Медь входа и PTC, медь +24V к LED | PASS (`verify_input_copper.py`, `verify_led_copper.py`) |
| Плоскость земли и пути возврата (`check_return_paths.py`) | PASS, подробности в README |
| Петли DC/DC (`analyze_dcdc_loops.py`) | PASS после C911, подробности в README |
| Архив совпадает с платой | OK |

Что нашёл `check_fab.py` на первой проверке и что исправлено: три переходных массива +24V стояли на площадке C901 (перенесены на 12 мест вне площадки; `reinforce_led.py`), девять одноцепных углов дорожек проходили у площадки на 0,03–0,085 мм без касания, и маска открывала их (объединены сегменты, угол LED2_RETURN у метки NT722 сдвинут на неё; `fab_touchups.py`), штрих шёлка 0,12–0,15 мм и шёлк ближе 0,15 мм к площадкам, отверстиям и переходным (`check_fab.py --fix-silk`, затем `fix_silk.py`; в `check_fab.py` текст сравнивается с линиями шёлка по штрихам, как в DRC, а не по рамке текста), подписи платы с версией «0.22» (теперь `CHEAP-1`).

## 4. Сборка вручную

Для оператора есть отдельные документы: [assembly/Assembly_cheap1_A4.pdf](assembly/Assembly_cheap1_A4.pdf) (4 страницы: схема установки A4 и таблица «позиции — MPN» отдельно для SMD и выводных деталей), схема SMD крупно на листе A3 — [assembly/Assembly_cheap1_SMD_A3.pdf](assembly/Assembly_cheap1_SMD_A3.pdf) — и подробная [assembly/Assembly_cheap1.pdf](assembly/Assembly_cheap1.pdf) (порядок, что куда ставить, полярность). Ниже — заметки по самой плате.

- Детали на нижней стороне: **C911** (100 нФ 0603 под U902, 1 шт; можно паять феном или паяльником сразу после установки U902, пока плата лежит вверх ногами) и держатель батарейки BT301.
- U601 теперь UCC27524ADR (SOIC-8); IRS4427S больше не нужна. ENA (вывод 1) соединён с +12V короткой перемычкой возле вывода: при пайке не соединить с соседним выводом 2 (HEATER_EN).
- L711 (DTMSS-27/0.047/15-V) стоит на ребре: выводы Ø1,9 мм (20 ± 5 мм по даташиту) подрезать после установки, зазор между тороидом и платой не больше 2 мм; корпус тороида лучше закрепить клеем или компаундом.
- R716 теперь 0,12 Ом (80 Вт), R715 остаётся 0,027 Ом. Шунт JIERR JER2512F3R120, C49164917: 1%, 3 Вт, 2512; источник и условия мощности — в README.
- Клеммник J901: KF301-5.0-2P (Cixi Kefa), по [странице LCSC](https://www.lcsc.com/product-detail/Screw-Terminal-Blocks_Cixi-Kefa-Elec-KF301-5-0-2P_C474881.html) 17 А / 250 В, провод 22–14 AWG (до 1,5 мм²). Расчётный максимум входа около 11,5 А (CH1 80 Вт, CH2, нагреватель 100 Вт, помпа, AUX), блок питания 24 В нужен от 250–300 Вт; провод к клеммнику ≥ 1,5 мм² и короткий.
- Список закупки и склада — [BOM_cheap1.csv](BOM_cheap1.csv), [BUY_cheap1.csv](BUY_cheap1.csv) (160 деталей, 94 со склада, 66 докупить; оценка заказа $33,86 без CR2032, доставки и налогов; предохранитель 10 А для F902 не закупается, только держатель XF-508P-B-B).

## 5. Перед заказом

1. Открыть `cheap-version.kicad_pcb` в KiCad (3D-вид, DRC) — автоматические проверки не заменяют просмотр глазами.
2. ~~Загрузить архив в JLCDFM~~ — сделано 04.10.2026, разбор отчёта в разделе 6.
3. Перед оплатой обновить цены и наличие по `BUY_cheap1.csv`: пять позиций сверены 04.10.2026, остальные цены взяты из снимка 28–30.09.2026; CR2032 приобретается отдельно.
4. Корпус (потолок около 40 мм под DTMSS, C901 Ø16, клеммники) пересобирается отдельно, см. `../enclosure/`.

## 6. Отчёт JLCDFM от 04.10.2026

[dfm.jlcdfm.com](https://dfm.jlcdfm.com), `cheap-version_cheap1_jlcpcb.zip`, только PCB DFM (SMT DFM не включался), 4 слоя, 10 × 10 см. В отчёте нет координат, места найдены сопоставлением с платой. Отчёт PDF лежит у пользователя, в репозиторий не добавлялся.

| Правило JLCDFM | Результат | Разбор |
|---|---|---|
| Ширина дорожки, зазор дорожек, зазор отверстия до дорожки, поясок, расстояние между площадками, острые углы, обрывы, дорожка и площадка до края, переходное в площадке и у площадки, перемычка маски, сверловка | замечаний нет или Good (дорожки 0,25 мм, зазор площадок 0,27, зазор отверстия до дорожки 0,39, поясок 0,17 мм) | — |
| **tht to smd** | **0,65 мм, Danger 18, Warning 18, Good 14** | Единственное правило с Danger, объяснение ниже |
| Solder mask opening exposing trace | 0,11 мм, Warning 1 (Good 57) | У PCB_V1 было Danger 1 и Warning 1. Остались одноцепные углы, где дорожка проходит у своей площадки на 0,09–0,12 мм без касания (Q601.2, R905.1, C712.1, R211.1, R908.1, C104.1); исправляются так же, как девять предыдущих (объединением сегментов), если понадобится |
| Negative soldermask expansion | 0,04 мм, Warning 52 | То же, что у PCB_V1 (50): отверстия маски совпадают с площадками 1:1, JLCPCB их принимает; расширение больше нуля сузило бы перемычки маски |
| Silkscreen to pad | 0,16 мм, Warning 54, Good 1 | Шёлк не ближе 0,15 мм к площадкам (норма JLCPCB); порог предупреждения JLCDFM не назван (судя по результату, выше 0,15 мм); в Gerber шёлк уже вычтен маской (`--subtract-soldermask`) |
| Silkscreen to hole | 0,15 мм, Warning 53, Good 6 | То же для отверстий и переходных |
| Silkscreen line width | 0,2 мм, Good 62 | — |

**tht to smd.** Измерение 0,65 мм на картинке отчёта совпадает с самой близкой парой «сквозная площадка — SMD-площадка» на плате: **L711.1 – C715.2** (по моему расчёту по контурам площадок это ровно 0,65 мм). Числа 18 / 18 / 14 сходятся, если Danger — пары ближе примерно 1,95 мм, а Warning — до примерно 2,9 мм (это моя догадка по числу пар, JLCPCB порог не называет). Пары ближе 1,95 мм: L711.1 – C715.2 (0,65), тактовые кнопки SW201 и SW202 (выводы THT) и соседние SMD-площадки ESP32 U201, C201, C203, R201, R202 (0,9–1,7 мм), держатель батарейки BT301 и TP103, C302, R304, F301 (1,06–1,7 мм), L711.2 – Q711 (1,93 мм). У PCB_V1 этих замечаний почти не было, потому что там кнопки SMD (TS-1187A) и L711 SMD, а у cheap-1 — кнопки со склада на сквозных выводах и тороид DTMSS.

Это норма для сборки (паяльная волна, выборочная пайка, зазор для оснастки), а не ограничение изготовления платы: между сквозной и SMD-площадкой остаётся не менее 0,65 мм меди-маски-меди. Плата паяется вручную, SMT-сборка JLCPCB не используется. Это моё заключение, JLCPCB его не подтверждал. Чтобы убрать эти замечания, пришлось бы заменить кнопки на SMD и сдвинуть C715, L711, BT301 и связанную разводку — на плате, рассчитанной на ручную пайку, смысла нет.

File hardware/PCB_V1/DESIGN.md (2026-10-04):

# PCB_V1 — описание схемы, ревизия 0.22

Текущая схема, расчётные допущения и открытые вопросы. История изменений и архив прежних отчётов — [CHANGELOG.md](CHANGELOG.md). Всё, что здесь сказано о соединениях, проверяется скриптами из `hardware/` (см. «Проверки»).

## Исходные данные

- Внешний БП **24 В**, уставка 24,0 В, не выше 25 В; расчётный диапазон силовой шины **21,6…25 В**.
- Нагрузки: PTC **24 В / 100 Вт**, помпа **24 В / около 6 Вт**, два 4-проводных PC-вентилятора **12 В**, LED-панель 16S18P (уставка 1,111 А) и две одинаковые «голые» LED-линейки под стабилизированный ток.
- ESP32-WROOM-32E, RTC PCF8563T с кварцем и резервной CR2032, microSD, SHT4x, поплавок. Назначение GPIO не менялось со времён 12-вольтовой версии. С 0.20 прошивка сама определяет микросхему часов (PCF8563 `0x51` или прежний DS3231 `0x68`), см. [RTC_COMPATIBILITY.md](RTC_COMPATIBILITY.md).
- Плата не больше 100×100 мм, без крепёжных отверстий; все разъёмы и microSD — по краям. Изготовитель JLCPCB, FR4, 4 слоя; **стек подтверждён пользователем: 1,6 мм, наружные слои 1 oz, внутренние 0,5 oz**. Все 170 компонентов (из них 4 net-tie без покупки) размещены внутри контура, батарейный держатель снизу. **Плата разведена** (01.10.2026, [ROUTING.md](ROUTING.md)). Правила и расположение — [PLACEMENT.md](PLACEMENT.md).

## Архитектура питания

```text
XT60 J901: 1=GND, 2=+24V
  +24V ─┬─ D901 SMBJ26CA, C901 220u/50V, C902
        ├─ F902 10 A ATM ─ +24V_LOADS ─┬─ PTC 24 V/100 W, Q601 (NTMFS5C628NL)
        │                             └─ F521 1 A ─ помпа 24 V/6 W, Q521 AO3422 + SS36
        ├─ C710 ─ F711 6.3 A ─ CH1 AL8853, панель 1,111 А
        │       └ F721 3 A ── CH2 AL8853, J721 ‖ J731 (0,465 А суммарно)
        └─ F904 3 A ─ AUX_VIN ─ LMR16020 (~526 kHz) ─ +12V ─┬─ F501/F511 1 A ─ вентиляторы
                                                           ├─ UCC27524A (затвор PTC ~12 В)
                                                           ├─ VIN обоих AL8853
                                                           └─ TPS54202 ─ +3V3 (логика)
```

- **Полярность** защищена только ключом разъёма XT60PW-M (вывод 1 «−», вывод 2 «+» по шелкографии посадочного места KiCad). Электронной защиты нет: неправильно собранный кабель выведет плату из строя. Кабель собирается один раз и проверяется мультиметром.
- **Участок XT60 — TVS — входная ёмкость не защищён предохранителем на плате**; нужна подходящая защита на стороне БП/кабеля.
- **+12V** — вспомогательная шина. Она отделяет от входных выбросов всё, что не рассчитано на 24 В с запасом: TPS54202 (≤28 В), UCC27524A (≤18 В), PC-вентиляторы, питание микросхем AL8853. Через 24 В идут только силовые дроссели LED, PTC и помпа.
- **LED-возвраты:** J721− и J731− соединены внутри CH2 и идут через шунт R726 на землю. Их нельзя соединять с J711− или с GND. При выключенном контроллере у boost остаётся путь вход — дроссель — диод — выход, поэтому КЗ на выходе ограничивают только F711/F721.

## LED-каналы

Расчёт — [LED_power_v22.txt](../review/LED_power_v22.txt): `analyze_led_power.py`, по 72 режима на канал (вход 21,6/24/25 В, Vf 40/44/48 В, 110/130 кГц, КПД 85/90 %, допуски FB и шунтов, снижение индуктивности). Это расчёт для выбора деталей, а не модель КПД и не гарантия защиты.

| Параметр | CH1, панель | CH2, обе линейки |
|---|---:|---:|
| Контроллер / ключ | AL8853 / AOD66923 (DPAK) | AL8853 / AOD66923 (DPAK) |
| Диод | SS5P10-M3/86A (TO-277A) | SS5P10-M3/86A (TO-277A) |
| Дроссель | SRP1770TA-470M | SRP1265A-470M |
| Шунт ключа / Rsl | 0,027 Ом / 1k | 0,047 Ом / 2,7k |
| Шунт тока LED | R716 0,18 Ом, FOJAN FRM252WFR180TM | R726 0,43 Ом |
| Ток номинальный / край допуска | 1,111 / 1,156 А | 0,465 / 0,484 А суммарно |
| Пик / RMS тока дросселя, макс. | 5,18 / 3,32 А | 3,08 / 1,63 А |
| Оценка OCP | 8,3…14,1 А | 3,9…7,9 А |
| Минимальный запас OCP над рабочим пиком | **3,14 А** | 0,94 А |
| Режимы | CCM, субгармоники ≤0,31 | DCM |
| Медь обмотки, 100 °C | 0,78 Вт | 0,31 Вт |
| Шунт ключа | 0,17 Вт | 0,07 Вт |
| Диод, проводимость (модель при 25 °C) | 1,05 Вт | 0,39 Вт |

Свет при 48 В: **75,66 Вт номинально / 78,72 Вт на границе допусков FB и шунтов**. Деление тока между двумя линейками CH2 не гарантируется; если одна оборвана, вторая получает не более 0,484 А. Затвор ключей получает около 12 В от питания AL8853. Насыщение дросселей в горячем состоянии, потери сердечника, пуск, OVP и компенсация петли расчётом не подтверждены.

## Компоненты и принятые решения

- **microSD:** HRO TF-01A (push-push). Пять подтяжек сохранены, отдельных ESD-сборок нет; карту менять при выключенной плате, риск статического разряда остаётся.
- **RTC:** PCF8563T, кварц FC-135 12,5 пФ, C304 18 пФ на OSCI. Резервное питание CR2032 через R307 1 кОм и D303 BAV170; зарядки нет. TP301 на CLKOUT служит для подбора C304. Схема питания, измерение частоты и ограничения — [RTC_COMPATIBILITY.md](RTC_COMPATIBILITY.md).
- **Выходные MLCC LED:** Murata GRM32EC72A106KE05L, X7S. По кривой Murata — 2,60 мкФ при 49 В, в модели 2,55 мкФ; эффективная ёмкость банка CH1 с допусками — 6,44 мкФ, расчётная граница пульсаций — 1,63 В p-p. Число конденсаторов без проверки петли и пульсаций не уменьшать. [Характеристики Murata](https://pim.murata.com/en-us/pim/details/?partNum=GRM32EC72A106KE05%23).
- **Измерение тока:** NT711/NT712/NT721/NT722 отделяют Kelvin-отводы от силовых площадок шунтов R715/R716/R725/R726.
- **L711:** SRP1770TA-470M сохранён. У рассмотренных дешёвых аналогов Isat 6,5–7,5 А; при принятом разбросе ограничения тока его снижение до этих значений опустило бы нижний порог ниже рабочего пика 5,2 А.

Текущие номиналы и MPN — [BOM.md](BOM.md). История замен и прежние цены — [CHANGELOG.md](CHANGELOG.md).

## Силовой путь и шина 12 В

Расчёт — [Power_path_v22.txt](../review/Power_path_v22.txt): `analyze_power_path.py`; сечения меди — [Copper_v22.txt](../review/Copper_v22.txt): `analyze_copper.py`.

- **PTC:** 4,17 А номинально, 4,79 А при холодном пуске (+15 %). Q601 при затворе ~12 В теряет 0,04–0,09 Вт.
- **Помпа:** 0,25 А номинально; в расчёте бюджет 0,5 А, реальный ток пуска и заклинивания не измерен.
- **TVS:** SMBJ26CA — рабочее 26 В > 25 В БП, ограничение 42,1 В при 14,3 А (10/1000 мкс, 25 °C). Запас до LMR16020 (65 В) — 22,9 В, до входных конденсаторов 50 В — 7,9 В. AL8853 на входной TVS больше не завязан. SMBJ26CA на стоке PTC (та же деталь, что D901) ограничивает до 42,1 В при VDS Q601 60 В; ключ помпы AO3422 (55 В) в худшем случае видит 42,9 В.
- **LMR16020:** делитель 150k/10k (0,1 %) даёт 12,000 В, статический разброс 11,74…12,26 В. Частота около 526 кГц (R906 47 кОм). Дроссель 22 мкГн PSPMAA0604-220M-ANP: пульсация ≤0,99 А p-p, пик ≤1,69 А при бюджете 1,2 А (потребность ~1,06 А). Минимальный порог тока микросхемы 2,5 А указан для 25 °C, максимальный 3,8 А ниже Isat дросселя 5 А; RMS обмотки 1,233 А при Irms 3,2 А, DCR ≤130 мОм. Выходная ёмкость: полимерный C909 25SVPF100M (100 мкФ/25 В) плюс керамический C910 22 мкФ. Без учёта C910 провал при ступени 0…1,2 А ≈0,18 В, пульсация ≈0,05 В p-p. Делитель EN 560k/47k: запуск ~14,9 В (13,0…17,3 В по разбросу порога).
- **TPS54202:** R101/R102 100k/22k 1%, 3,305 В номинально, 3,170…3,444 В статически при разбросе FB и сопротивлений. L101 FXL0630-100-M 10 мкГн: расчётный пик 1,496 А, RMS 1,040 А при бюджете логики 1 А; Isat 4,9 А / Irms 3,8 А при 25 °C — выше предела тока TPS54202 (не более 4,3 А). Выбросы нагрузки, дрейф и тепловой режим проверить на прототипе.
- **Входной ток платы:** ~11 А в худшем расчётном сценарии; БП 300 Вт = 12,5 А.

## Предохранители

Загрузка — с коэффициентом 0,75 (длительный ток) × 0,90 (запас на горячую плату, проектное допущение).

| Ref | Выбор | Допустимо с коэффициентами | Расчётная нагрузка |
|---|---|---:|---:|
| F902 | держатель XF-508P-B-B, вставка ATM 10 А | 6,75 А | 5,82 А (PTC + помпа) |
| F711 | Littelfuse 045106.3MRL, 6,3 А | 4,25 А | 3,32 А RMS |
| F721 | Littelfuse 0451003.MRL, 3 А | 2,03 А | 1,63 А RMS |
| F904 | Littelfuse 0451003.MRL, 3 А | 2,03 А | 1,09 А RMS |
| F501/F511 | Littelfuse 0451001.MRL, 1 А | 0,68 А каждый | 0,34 А каждый |
| F521 | Littelfuse 0451001.MRL, 1 А | 0,68 А | 0,50 А (бюджет) |

Отключающая способность, I²t и избирательность с реальным БП и кабелями не проверены. Вставка F902 — Littelfuse 0297010.WXNV (MINI 10 А, 32 В, отключает 1000 А при 32 В), см. [PRE_LAYOUT_PARTS_REVIEW.md](https://github.com/nikolajevs/ai/blob/1887d866ac820a41e9d1717056d188d7af6e6b51/pcb/PCB_V1/PRE_LAYOUT_PARTS_REVIEW.md). Площадки Littelfuse 451 — 1,96×3,15 мм по рекомендации производителя.

## Проверки

Запуск: `python check_all.py` из папки `hardware`; требования к окружению и обновление отчётов — [../README.md](../README.md).

| Проверка | Состояние ревизии 0.22 |
|---|---|
| ERC / DRC | 0 ошибок и предупреждений ERC; 0 нарушений и несоединённых связей DRC |
| Схема и плата | 116 групп соединений, 15 GPIO; 170 посадочных мест и 444 вывода сверены со схемой |
| Размещение и трассировка | Контур, доступ к разъёмам, модели, антенна, земля In1, узлы SW, Kelvin-линии и RTC; [ROUTING.md](ROUTING.md) |
| DFM | 0 FAIL, два предупреждения; повторная проверка JLCDFM не подтверждена — [FAB.md](FAB.md) |
| Расчёты и BOM | Отчёты и заказные файлы сверяются со схемой и датированными снимками цен |

Сохранённые результаты — [../review/](../review/). Проверки геометрии и связности не подтверждают устойчивость преобразователей и тепловой режим.

## Стоимость

По снимку 28–30.09.2026: **$30,04 компонентов на плату**, $28,42 при пяти платах. Это стоимость установленных деталей, а не корзины с минимальными партиями.

Заказ LCSC с минимальными партиями: **$59,92 на одну плату / $148,58 на пять**, без XT60, CR2032, доставки и налогов. Заказные файлы и исключения — [BOM.md](BOM.md); полный расчёт — [BOM_cost_v22.txt](../review/BOM_cost_v22.txt).

Первые платы собираются вручную: все SMT сверху, снизу THT-держатель батарейки. Оценка альтернативной сборки — [JLC_assembly_v22.txt](../review/JLC_assembly_v22.txt).

## Корпус

Печатный корпус из двух деталей (основание и крышка) лежит в [../enclosure/](../enclosure/README.md): настенное крепление ушками, вентиляция, FDM из PLA, защёлки без винтов. Плата без крепёжных отверстий лежит на опорах и прижимается рёбрами крышки; окна вырезаны по габаритам разъёмов из STEP платы, разъёмы J301 и J201 и кнопки BOOT/RESET доступны через потолок. По проверке STEP корпус и плата не пересекаются, минимальный зазор 0,65 мм. Корпус не печатался: посадку защёлок проверять на фрагментах-купонах.

## Открытые вопросы

1. **Закупка и образцы.** XT60PW-M на LCSC нет — покупать у другого поставщика; SRP1770TA-470M на LCSC было 26 шт. (28.09) — купить заранее; наличие перед покупкой проверить заново. На образцах проверить полярность и вылет XT60, клеммы и держатели, сторону ввода батарейки BT301 и **высоту F902 со вставкой**: сейчас она расчётная (17,15 мм), для корпуса закладывать не меньше 18 мм (потолок корпуса 21,0 мм, `Z_CEIL` в `enclosure/enclosure.py`); после измерения поправить `shoulder` в `fuseholder()` (`models3d/mechanical.py`), пересоздать STEP и повторить `enclosure/check_enclosure.py`. Есть оценка по датированному снимку; итоговая цена заказа ещё не подтверждена.
2. **Плата и производство.** Gerber подготовлены, локальные DFM-замечания исправлены; остаются повторная загрузка в JLCDFM и независимый просмотр Gerber — [FAB.md](FAB.md). В трассировке остаются два расчётных вопроса: HEATER_DRAIN 3,1 мм при требовании 3,02 мм и общая дорожка +12V к вентиляторам 0,5 мм на In2 (наружный расчёт к ней неприменим; при 0,682 А и толщине из файла платы 0,0152 мм требуется около 1,06 мм по принятой оценке IPC-2221, ΔT 10 °C). Это оценка сечения, не измерение температуры. Осмотр платы и проверка механики пользователем ещё не подтверждены.
3. На прототипе:
   - пуск, OVP и компенсация обоих boost; VGS при питании AL8853 от 12 В;
   - нагрев дросселей, ключей и TVS; нагрев SS5P10 в CH1 — цель: подъём ниже 50 °C с полигоном меди на катоде;
   - пуск и загрузка LMR16020; L902 PSPMAA0604 (новый производитель): индуктивность, нагрев при полной нагрузке 12 В, звон на SW; L101 FXL0630: нагрев и пульсации 3,3 В;
   - реакция защиты реального БП и предохранителей;
   - ток пуска и заклинивания помпы;
   - частота кварца RTC на TP301 (прошивка с `RTC_CLKOUT_TRIM 1`) и подбор C304, флаг VL после снятия батарейки;
   - батарейный узел RTC (D303 BAV170, R307) остаётся PROTOTYPE: RTC_VDD при +3V3 = 3,17/3,30/3,44 В, свежем и частично разряженном элементе; ток CR2032 в обоих направлениях при включённой и выключенной плате; сохранение времени и VL при пропадании и возврате питания; то же при крайних температурах;
   - фронты UART через R205/R206 1 кОм и реальная скорость прошивки с кабелем программатора.
4. PTC требует отдельного термостата или термопредохранителя с подходящим DC-рейтингом. На плате его нет.

## Источники

- [Diodes AL8853](https://www.diodes.com/assets/Datasheets/AL8853.pdf): VIN, FB/OCP, рампа, защиты.
- [TI LMR16020](https://www.ti.com/lit/ds/symlink/lmr16020.pdf): выводы, FB, предел тока, выбор ёмкости, пуск.
- [AOS AOD66923](https://www.aosmd.com/res/datasheets/AOD66923.pdf): Rds(on), заряды затвора, площадка DPAK.
- [Vishay SS5P10](https://www.vishay.com/docs/88984/ss5p10.pdf): VF, утечка, тепловое сопротивление, площадка TO-277A.
- [Bourns SRP1770TA](https://www.bourns.com/docs/Product-Datasheets/SRP1770TA.pdf), [SRP1265A](https://www.bourns.com/docs/product-datasheets/srp1265a.pdf): DCR, токи, посадочные места.
- cjiang FXL0630 ([LCSC C167223](https://www.lcsc.com/product-detail/C167223.html)), PROD Tech PSPMAA0604 ([LCSC C53190553](https://www.lcsc.com/product-detail/C53190553.html)): DCR, Isat, Irms, площадки.
- [Panasonic SVPF / 25SVPF100M](https://industrial.panasonic.com/ww/products/pt/os-con/models/25SVPF100M): ёмкость, ESR, корпус E7.
- [AOS AO3422](https://www.aosmd.com/sites/default/files/res/datasheets/AO3422.pdf): 55 В, RDS при затворе 2,5 В.
- [Littelfuse 451/453](https://www.littelfuse.com/assetdocs/fuse-451-and-453-datasheet?assetguid=533cd5cc-956c-4243-867f-6ab5a62f6ba1): предохранители и площадки.
- [Vishay SMBJ](https://www.vishay.com/docs/88392/smbj.pdf), [SS36](https://www.vishay.com/docs/88751/ss32.pdf): импульсные и тепловые условия.
- [Amass XT60PW-M](https://www.tme.eu/Document/b13629717d44ae038681dba08d18c0b6/XT60PW-M.pdf), XFCN XF-508P-B-B (чертёж LCSC C19727305).
- [NXP PCF8563](https://www.nxp.com/docs/en/data-sheet/PCF8563.pdf), Rev. 11.1: регистры, генератор, питание. Схема RTC и прошивка — [RTC_COMPATIBILITY.md](RTC_COMPATIBILITY.md).

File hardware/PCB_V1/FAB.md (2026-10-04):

# PCB_V1 — файлы для производства на JLCPCB, ревизия 0.22

01.10.2026, ветки `pcb-fab` и `pcb-dfm-fixes`. Разведённая плата ([ROUTING.md](ROUTING.md)) экспортирована в Gerber и сверловку; архив для загрузки — [../fab/PCB_V1_v22_jlcpcb.zip](../fab/PCB_V1_v22_jlcpcb.zip). Первый архив был проверен автоматическим анализатором JLCPCB (JLCDFM, отчёт прислал пользователь): он нашёл замечания по шёлкографии, маске и переходным отверстиям. Они устранены в плате и в архиве (раздел 3); **повторная загрузка архива в JLCDFM покажет, что осталось**.

## 1. Что в архиве

12 файлов, Gerber RS-274X (X2, формат 4.6, мм, расширения Protel) и Excellon:

| Файл | Содержимое |
|---|---|
| `PCB_V1-F_Cu.gtl`, `PCB_V1-In1_Cu.g1`, `PCB_V1-In2_Cu.g2`, `PCB_V1-B_Cu.gbl` | четыре слоя меди (In1 — земля, In2 — сигналы и +3V3) |
| `PCB_V1-F_Mask.gts`, `PCB_V1-B_Mask.gbs` | паяльная маска; отверстия равны площадкам (1:1), переходные закрыты маской |
| `PCB_V1-F_Silkscreen.gto`, `PCB_V1-B_Silkscreen.gbo` | шёлкография (штрих 0,2 мм, не ближе 0,15 мм к площадкам и отверстиям) |
| `PCB_V1-F_Paste.gtp` | паста сверху (для трафарета; нижней пасты нет — снизу только THT-держатель батарейки) |
| `PCB_V1-Edge_Cuts.gm1` | контур 100,000 × 100,000 мм (линия 0,05 мм по осевой) |
| `PCB_V1-PTH.drl`, `PCB_V1-NPTH.drl` | сверловка: металлизированные (329 отверстий, 8 диаметров, 2 фрезерованных паза) и неметаллизированные (2 × Ø1,0 мм, гнездо TF-01A) |

В заголовках файлов дата и версия KiCad заменены константами (`2000-01-01`, `10.0.0`), чтобы повторный экспорт давал тот же архив байт в байт.

## 2. Параметры заказа

Значения для формы заказа на [jlcpcb.com](https://jlcpcb.com/quote); названия пунктов у JLCPCB со временем меняются, сверьте по форме.

| Пункт | Значение | Почему |
|---|---|---|
| Base material / Layers | FR-4, **4** | |
| Dimensions | **100 × 100 мм** | нижняя ценовая категория JLCPCB; JLCDFM определил размер как 10 × 10 см |
| PCB Qty | 5 (минимум) | |
| Delivery format | Single PCB | панелизации нет |
| PCB Thickness | **1,6 мм** | стек подтверждён |
| Layer stack-up | стандартный 4-слойный 1,6 мм (JLC04161H-7628) | в проекте задан JLC7628; импеданс не контролируется |
| Outer / Inner copper weight | **1 oz / 0,5 oz** | подтверждённый стек, у JLCPCB это стандарт |
| Surface finish | HASL (со свинцом или без), ENIG — по желанию | первые платы паяются вручную: HASL проще и дешевле; ENIG даёт ровные площадки |
| Solder mask / Silkscreen | любой цвет / белый | |
| Via covering | Tented (по умолчанию) | в файлах маски на переходных нет отверстий |
| Min via hole size / diameter | **0,3 мм / 0,4 мм** (по умолчанию) | наши переходные 0,3/0,65 и 0,4/0,8 мм подходят без доплаты |
| Impedance control, edge plating, castellated holes, gold fingers, edge rails | нет | |
| Remove order number | по желанию | по умолчанию JLCPCB печатает номер заказа на шёлке; чтобы задать место, в шёлк кладётся текст `JLCJLCJLCJLC` (в плате его нет) |
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

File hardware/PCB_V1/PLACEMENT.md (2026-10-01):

# Размещение 0.22

Плата 100×100 мм, без крепёжных отверстий; 170 компонентов, включая четыре net-tie. Разъёмы и microSD по краям, батарейный держатель снизу. Трассировка завершена; при DFM-доводке F301 сдвинут на 0,1 мм, остальные позиции сохранены. Текущее состояние — [ROUTING.md](ROUTING.md), производственные исправления — [FAB.md](FAB.md).

**3D-модели.** Все детали платы имеют 3D-модели в `libraries/GrowBox.3dshapes/`. Силовые SMD и microSD строит `../models3d/power.py` ([SOURCES_power.md](libraries/GrowBox.3dshapes/SOURCES_power.md)). Разъёмы, держатели и кнопки строит `../models3d/mechanical.py` ([SOURCES_mechanical.md](libraries/GrowBox.3dshapes/SOURCES_mechanical.md)). На плату их привязывает `../sync_models.py`, а `verify_placement.py` проверяет, что у каждой детали есть модель. Самые высокие детали: F902 со вставкой — расчётно 17,15 мм (не измерено, для корпуса закладывать не меньше 18 мм), клеммы KANGNEX — 14,07 мм, DORABO — 8,6 мм, XT60 — 8,4 мм, L711 — 6,7 мм. Снизу BT301 — 4,1 мм. Net-tie NT712 и NT722 сдвинуты на 0,1 мм от шунтов R716/R726: зазор до площадок возврата LED стал 0,55 мм при норме класса LED48 0,5 мм.
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

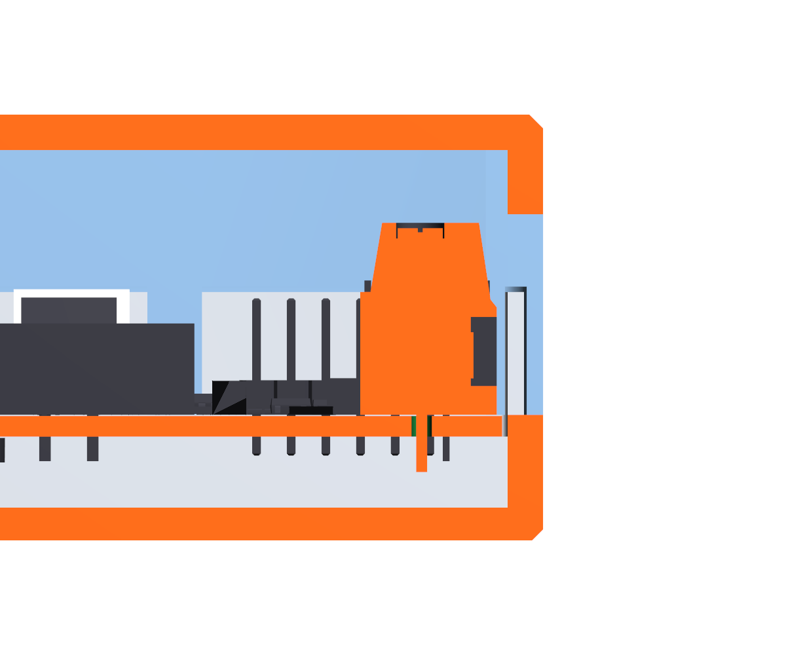
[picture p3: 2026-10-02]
hardware/enclosure/renders/section_front.png

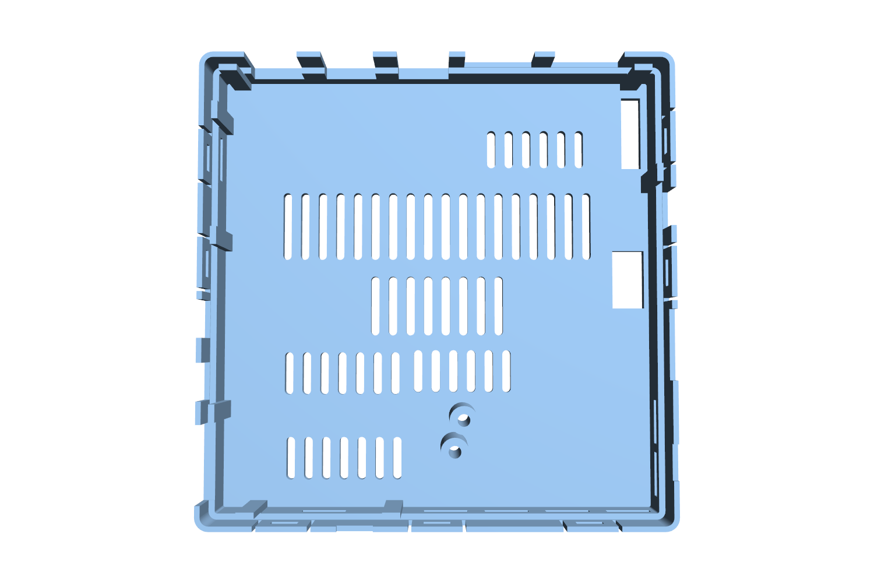
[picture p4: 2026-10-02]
hardware/enclosure/renders/lid_inside.png

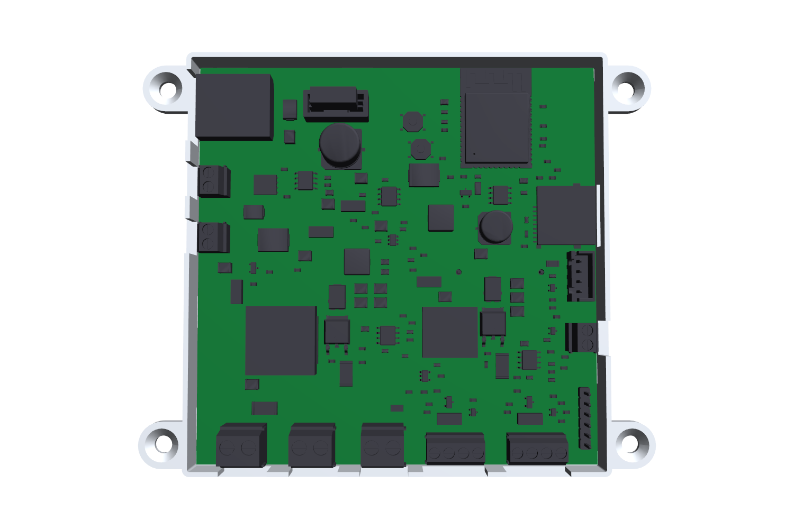
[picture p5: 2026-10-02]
hardware/enclosure/renders/open_top.png

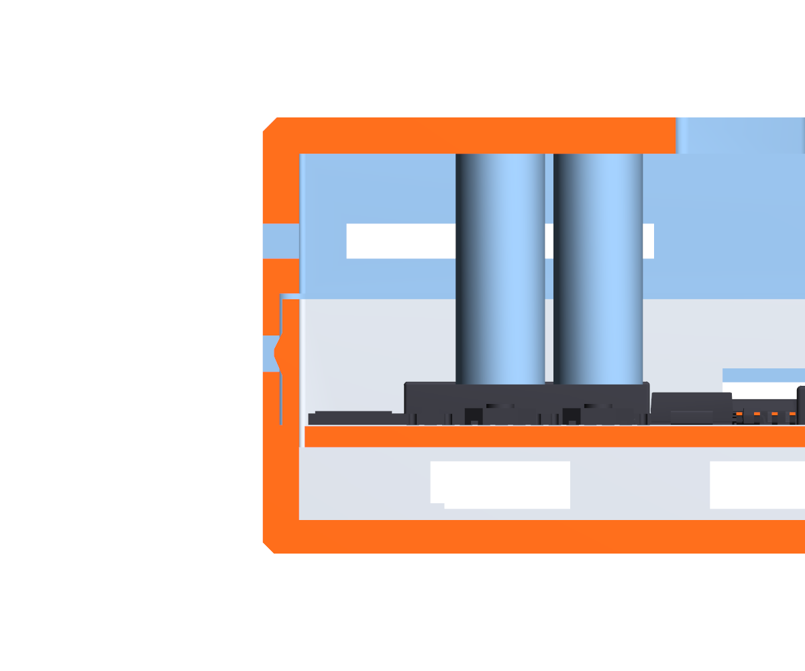
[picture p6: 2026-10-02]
hardware/enclosure/renders/section_snap.png

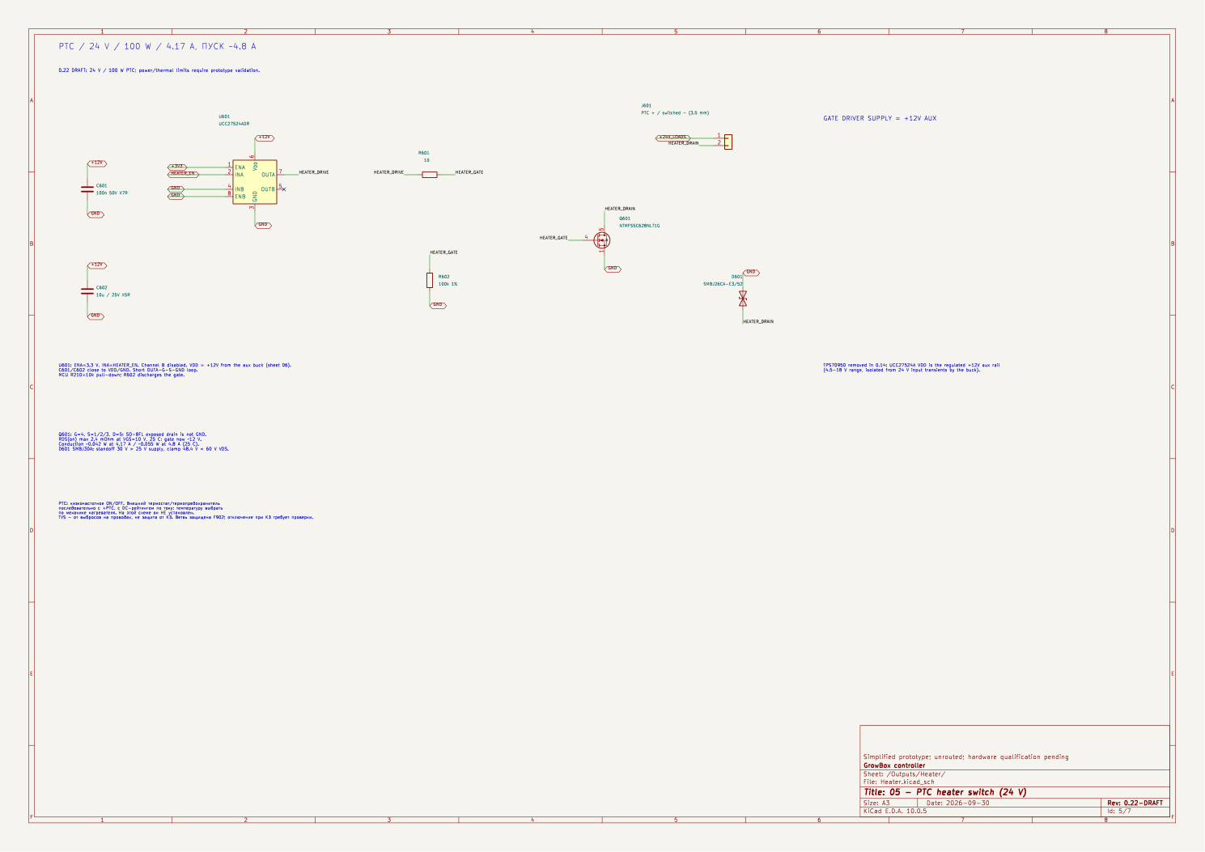
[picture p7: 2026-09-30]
hardware/review/Heater_v22.png

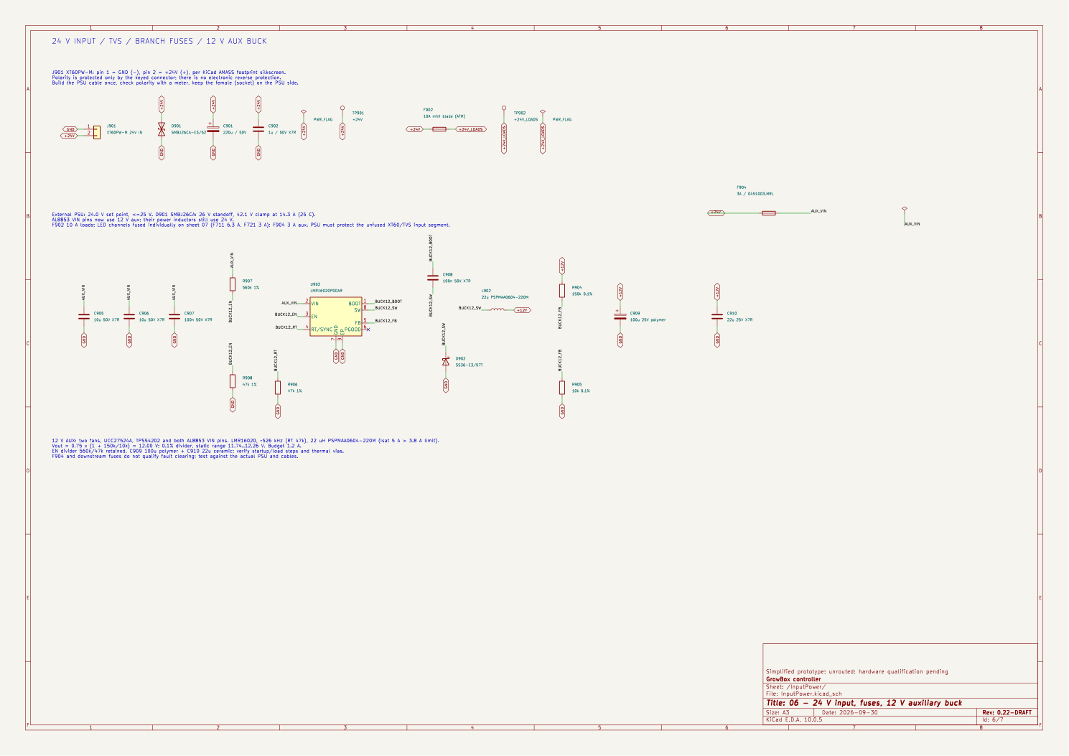
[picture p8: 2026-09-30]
hardware/review/InputPower_v22.png

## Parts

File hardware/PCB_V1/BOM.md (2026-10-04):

# PCB_V1 — BOM для заказа на LCSC, ревизия 0.22

Заказной BOM собирается скриптом [`export_lcsc_bom.py`](../export_lcsc_bom.py) из схемы и датированного снимка цен LCSC ([price_snapshot_v22.json](price_snapshot_v22.json), 28–30.09.2026); `check_all.py` проверяет, что файлы совпадают со схемой и снимком.

| Файл | Для чего |
|---|---|
| [BOM_LCSC_v22.csv](BOM_LCSC_v22.csv) | **Загрузка на [lcsc.com/bom](https://www.lcsc.com/bom)**: 66 позиций (количество на одну плату), колонки `Quantity`, `LCSC Part Number`, `Manufacturer Part Number`, `Manufacturer`, `Description`, `Customer Part Number` (обозначения на плате) |
| [BOM_LCSC_v22.xlsx](BOM_LCSC_v22.xlsx) | То же и для чтения: листы «LCSC upload», «Full BOM» (все колонки, цены, остатки, пометки) и «Summary» (итоги и что купить отдельно) |
| [BOM_PCB_V1_v22.csv](BOM_PCB_V1_v22.csv) | Полный BOM одной таблицей: упаковка, тип монтажа, класс JLCPCB, остаток и минимальная партия LCSC, количества и цены для 1 и 5 плат, пометки; детали, которые не покупаются (DNP, тестовые площадки, net-tie), — в конце |

## Как заказать

1. Откройте [lcsc.com/bom](https://www.lcsc.com/bom) и загрузите `BOM_LCSC_v22.csv` (или `.xlsx`; LCSC принимает `.csv`, `.xls`, `.xlsx` до 4 МБ и до 800 строк).
2. В окне сопоставления колонок укажите: `Quantity` → Quantity (обязательно), `LCSC Part Number` → LCSC Part Number, `Manufacturer Part Number` → Mfr. Part Number, `Description` → Description. Чем больше колонок сопоставлено, тем точнее поиск; `Customer Part Number` — по желанию, это обозначения на плате.
3. Проверьте найденные позиции: LCSC покажет **текущие** цены и остатки (в файле — снимок 28–30.09), количества можно править прямо в списке.

## Количества

В файле — **количество на одну плату**: те же числа, что в схеме (159 деталей, 66 позиций), без запаса и без округления до минимальных партий LCSC. Минимальная партия и кратность каждой позиции — в колонках «LCSC minimum» и «LCSC multiple» полного BOM: например, резисторы и конденсаторы 0603 LCSC продаёт сотнями, TPS54202 — по пять. Если LCSC при загрузке покажет, что количество меньше минимального, поправьте его в списке.

Для справки в полном BOM посчитан заказ с учётом минимальных партий (цены по снимку, без доставки, налогов и скидок):

| Заказ | USD |
|---|---:|
| 1 плата | 59,92 |
| 5 плат | 148,58 |

В расчёт входит 66 кодов LCSC. Расхождение с [BOM_cost_v22.txt](../review/BOM_cost_v22.txt) ($151,62 на пять плат) — это пять XT60 по $0,61, которых в файле нет; батарейка в снимке цен без цены. Файл на другое число плат или с запасом: `python export_lcsc_bom.py ... --boards 5 --spare-rate 0.1` (запас 10 %, не меньше одной штуки).

## Чего нет в файле

- **J901, разъём питания Amass XT60PW-M (C98732).** На 28.09 на LCSC 0 в наличии, поэтому в загрузку он не включён; купить у другого поставщика (на JLCPCB в библиотеке деталей он есть, 8708 шт., но это для их сборки). Женская версия не подходит: под напряжением остались бы открытыми контакты кабеля блока питания.
- **Батарейка CR2032** для BT301: на LCSC не найдена, купить в магазине. В файле только держатель MYOUNG BS-07-A1BJ001.
- Не покупаются: C106 (не устанавливается), тестовые площадки TP*, net-tie NT7** — это медь на плате.

## На что обратить внимание

- **Дроссель L711 SRP1770TA-470M (C2041872):** на LCSC 26 шт. на 28.09; заказать, не откладывая.
- **12 строк — «эквивалент допустим»** (колонка «Part type» в полном BOM): резисторы 0603, конденсаторы C203/C302 и C712–C724, PTC F301 и два штыревых разъёма (UART 2,54 мм J201 и JST XH J301) выбраны как представительные детали LCSC под нужный номинал и корпус; равноценная замена с теми же номиналом, корпусом и допуском подходит.
- **D301, D302, D501, D511:** оригинал (TI TPD2E2U06DCKR) на LCSC закончился, в заказе второй источник TECH PUBLIC TPD2E2U06DCKR-TP (C5350871).
- **Предохранитель F902:** держатель XF-508P-B-B и сам автомобильный предохранитель Littelfuse 0297010.WXNV (C151094) — две разные позиции; вторая в схеме не значится и добавлена как отдельная строка.
- Цены и остатки состарятся; перед заказом сверьте их на странице LCSC. Если после загрузки LCSC пометит позицию как недоступную, замена должна сохранить корпус и параметры из колонок «Value» и «Package» полного BOM.

## Как пересоздать

Из папки `hardware`, обычный Python 3 (KiCad нужен только для экспорта netlist):

```text
python check_all.py            # проверка, что BOM совпадает со схемой и снимком цен
python check_all.py --write    # обновить файлы BOM (и остальные отчёты)
python export_lcsc_bom.py netlist.xml PCB_V1/price_snapshot_v22.json PCB_V1/jlc_snapshot_v22.json PCB_V1 --rev v22 [--boards 1] [--spare-rate 0]
```

После замены детали в схеме, смены номера LCSC или обновления цен нужно обновить снимок `price_snapshot_v22.json` (запись со ссылкой на страницу LCSC), затем заново собрать BOM.

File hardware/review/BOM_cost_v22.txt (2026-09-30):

PCB_V1 v0.22 BOM price audit, LCSC snapshot 2026-09-28 (base); 2026-09-29 (v18/v19); 2026-09-30 (v20-v22 parts)
LCSC product pages, list price per tier (promotional discounts ignored), stock/minimum/multiple as shown. EUR at ECB 2026-09-28: 1 EUR = 1.1378 USD.
Per board = fitted parts x tier price; order = LCSC minimum/multiple applied (leftovers included).
Priced on-board purchasing codes: 66; fitted on-board parts: 159 (DNP and copper test pads excluded).
Not included: shipping, VAT/duty, PCB, assembly, promotional discounts, parts marked unpriced.

refs                           qty       LCSC kind        USD@1  1 board  order 1    USD@5 5: /board  order 5  part
J901                             1     C98732 mpn        0.6072   0.6072   0.6072   0.6072    0.6072   3.0360  Amass XT60PW-M
D601,D901                        2    C515606 mpn        0.1036   0.2072   0.5180   0.1036    0.2072   1.0360  Vishay SMBJ26CA-E3/52
C901                             1    C178549 mpn        0.5157   0.5157   0.5157   0.5157    0.5157   2.5785  Panasonic EEEFK1H221P
C902                             1     C40708 mpn        0.1312   0.1312   0.6560   0.1312    0.1312   0.6560  Samsung CL32B105KBHNNNE
F902                             1  C19727305 mpn        0.2775   0.2775   1.3875   0.2775    0.2775   1.3875  XFCN XF-508P-B-B
(not in schematic)               1    C151094 extra      0.1236   0.1236   0.6180   0.1236    0.1236   0.6180  Littelfuse 0297010.WXNV (F902 insert)
U902                             1    C190006 mpn        0.8159   0.8159   0.8159   0.8159    0.8159   4.0795  TI LMR16020PDDAR
D521,D902                        2     C35722 mpn        0.3327   0.6654   1.6635   0.3327    0.6654   3.3270  Vishay SS36-E3/57T
C521,C710,C715,C725,C905,C906    6    C386166 mpn        0.2929   1.7574   2.9290   0.2929    1.7574   8.7870  Taiyo Yuden UMK325AB7106KMHP
C102..C908 (10)                 10      C1591 mpn        0.0085   0.0850   0.8500   0.0085    0.0850   0.8500  Samsung CL10B104KB8NNNC
C909                             1    C136279 mpn        0.8670   0.8670   0.8670   0.8670    0.8670   4.3350  Panasonic 25SVPF100M
C101,C910                        2    C309062 mpn        0.3569   0.7138   0.7138   0.2814    0.5628   2.8140  Samsung CL32B226KAJNNNE
R904                             1    C326734 mpn        0.0437   0.0437   0.8740   0.0437    0.0437   0.8740  Yageo RT0603BRD07150KL
R905                             1     C95204 mpn        0.0330   0.0330   0.6600   0.0330    0.0330   0.6600  Yageo RT0603BRD0710KL
R907                             1     C23203 mpn        0.0015   0.0015   0.1500   0.0015    0.0015   0.1500  UNI-ROYAL 0603WAF5603T5E
U101                             1    C191884 mpn        0.1742   0.1742   0.8710   0.1742    0.1742   0.8710  TI TPS54202DDCR
C104,C105,C401                   3     C29277 mpn        0.0824   0.2472   0.8240   0.0824    0.2472   1.6480  Samsung CL21A226MPQNNNE
C201,C602                        2     C15850 mpn        0.0798   0.1596   1.5960   0.0798    0.1596   1.5960  Samsung CL21A106KAYNNNE
C203,C302                        2     C29936 generic    0.0178   0.0356   0.1780   0.0178    0.0356   0.1780  Samsung CL10B105KA8NNNC
U201                             1    C701341 mpn        3.7644   3.7644   3.7644   3.7644    3.7644  18.8220  Espressif ESP32-WROOM-32E-N4
BT301                            1   C2979167 mpn        0.3983   0.3983   1.9915   0.3983    0.3983   1.9915  MYOUNG BS-07-A1BJ001
J201                             1     C37208 generic    0.0419   0.0419   0.4190   0.0419    0.0419   0.4190  BOOMELE 2.54-1x6P
J301                             1    C144395 generic    0.0622   0.0622   0.6220   0.0622    0.0622   0.6220  JST B4B-XH-A(LF)(SN)
J401                             1     C91145 mpn        0.1937   0.1937   0.9685   0.1937    0.1937   0.9685  HRO TF-01A (Korean Hroparts Elec)
D301,D302,D501,D511              4   C5350871 clone      0.1131   0.4524   0.5655   0.1131    0.4524   2.2620  TECH PUBLIC TPD2E2U06DCKR-TP
F301                             1     C70065 generic    0.0307   0.0307   0.6140   0.0307    0.0307   0.6140  TECHFUSE nSMD010
SW201,SW202                      2    C318884 mpn        0.0207   0.0414   0.4140   0.0207    0.0414   0.4140  XKB TS-1187A-B-A-B
R201..R728 (19)                 19     C25804 generic    0.0019   0.0361   0.1900   0.0019    0.0361   0.1900  UNI-ROYAL 0603WAF1002T5E
R204..R712 (8)                   8     C21190 mpn        0.0026   0.0208   0.2600   0.0026    0.0208   0.2600  UNI-ROYAL 0603WAF1001T5E
R301,R302                        2     C23162 generic    0.0028   0.0056   0.2800   0.0028    0.0056   0.2800  UNI-ROYAL 0603WAF4701T5E
R303..R521 (9)                   9     C23140 generic    0.0025   0.0225   0.2500   0.0025    0.0225   0.2500  UNI-ROYAL 0603WAF330JT5E
R101..R723 (7)                   7     C25803 mpn        0.0031   0.0217   0.3100   0.0031    0.0217   0.3100  UNI-ROYAL 0603WAF1003T5E
R601,R711,R721                   3     C22859 generic    0.0032   0.0096   0.0640   0.0032    0.0096   0.0640  UNI-ROYAL 0603WAF100JT5E
R703,R906,R908                   3    C105579 mpn        0.0031   0.0093   0.3100   0.0031    0.0093   0.3100  Yageo RC0603FR-0747KL
R717,R727                        2     C25814 generic    0.0025   0.0050   0.2500   0.0025    0.0050   0.2500  UNI-ROYAL 0603WAF3163T5E
R722                             1     C13167 generic    0.0033   0.0033   0.3300   0.0033    0.0033   0.3300  UNI-ROYAL 0603WAF2701T5E
Q501,Q511                        2     C20917 mpn        0.0853   0.1706   0.4265   0.0853    0.1706   0.8530  AOS AO3400A
Q521                             1     C37130 mpn        0.1356   0.1356   0.6780   0.1356    0.1356   0.6780  AOS AO3422
F501,F511,F521                   3      C3099 mpn        0.2536   0.7608   1.2680   0.2536    0.7608   3.8040  Littelfuse 0451001.MRL
J302,J521,J601                   3    C466970 mpn        0.1832   0.5496   0.9160   0.1832    0.5496   2.7480  DORABO DB125-3.5-2P-GN-S
J501,J511                        2   C2757925 mpn        0.4026   0.8052   2.0130   0.4026    0.8052   4.0260  DORABO DB125-3.5-4P-GN-S
Q601                             1    C145537 mpn        0.7717   0.7717   0.7717   0.7717    0.7717   3.8585  onsemi NTMFS5C628NLT1G
U601                             1    C185857 mpn        0.2783   0.2783   1.3915   0.2783    0.2783   1.3915  TI UCC27524ADR
U700                             1      C7666 mpn        0.0496   0.0496   0.4960   0.0496    0.0496   0.4960  TI SN74LVC1G08DBVR
U710,U720                        2   C3192318 mpn        0.9392   1.8784   1.8784   0.7339    1.4678   7.3390  Diodes AL8853S-13
L711                             1   C2041872 mpn        2.9304   2.9304   2.9304   2.9304    2.9304  14.6520  Bourns SRP1770TA-470M
L721                             1    C840530 mpn        1.1226   1.1226   1.1226   1.1226    1.1226   5.6130  Bourns SRP1265A-470M
C711,C721                        2     C28323 mpn        0.0401   0.0802   0.4010   0.0401    0.0802   0.4010  Samsung CL21B105KBFNNNE
C712,C713,C722,C723              4     C14858 generic    0.0087   0.0348   0.4350   0.0087    0.0348   0.4350  Samsung CL10C101JB8NNNC
C714,C724                        2     C64705 generic    0.0183   0.0366   0.9150   0.0183    0.0366   0.9150  Samsung CL10B224KB8NNNC
C716..C728 (7)                   7    C576517 mpn        0.5519   3.8633   3.8633   0.4156    2.9092  14.5460  Murata GRM32EC72A106KE05L
R715                             1  C19633795 mpn        0.1011   0.1011   0.1011   0.1011    0.1011   0.5055  UNI-ROYAL LR123WF270MT4E
R716                             1  C48533605 mpn        0.0722   0.0722   0.7220   0.0722    0.0722   0.7220  FOJAN FRM252WFR180TM
R725                             1  C52015951 mpn        0.0495   0.0495   0.4950   0.0495    0.0495   0.4950  RVR HIXD25NR047F
R726                             1  C22464907 mpn        0.0270   0.0270   0.5400   0.0270    0.0270   0.5400  TA-I RLH12FTCR430
F711                             1    C178982 mpn        0.2477   0.2477   1.2385   0.2477    0.2477   1.2385  Littelfuse 045106.3MRL
F721,F904                        2     C13982 mpn        0.2556   0.5112   1.2780   0.2556    0.5112   2.5560  Littelfuse 0451003.MRL
J711,J721,J731                   3      C8465 mpn        0.1349   0.4047   0.6745   0.1349    0.4047   2.0235  KANGNEX WJ500V-5.08-2P
R102                             1     C31850 mpn        0.0042   0.0042   0.4200   0.0042    0.0042   0.4200  UNI-ROYAL 0603WAF2202T5E
U301                             1      C7440 mpn        0.6138   0.6138   0.6138   0.6138    0.6138   3.0690  NXP PCF8563T/5,518
Y301                             1     C32346 mpn        0.1733   0.1733   0.8665   0.1733    0.1733   0.8665  Epson Q13FC13500004 (FC-135 32.768 kHz, CL 12.5 pF, +/-20 ppm)
C304                             1      C1647 mpn        0.0159   0.0159   0.7950   0.0159    0.0159   0.7950  Samsung CL10C180JB8NNNC
D303                             1     C68970 mpn        0.0301   0.0301   0.6020   0.0301    0.0301   0.6020  JSCJ BAV170
Q711,Q721                        2    C485687 mpn        0.4343   0.8686   0.8686   0.3853    0.7706   3.8530  AOS AOD66923
D711,D721                        2     C46986 mpn        0.2871   0.5742   1.4355   0.2871    0.5742   2.8710  Vishay SS5P10-M3/86A
L101                             1    C167223 mpn        0.1695   0.1695   0.8475   0.1695    0.1695   0.8475  cjiang FXL0630-100-M
L902                             1  C53190553 mpn        0.1242   0.1242   0.6210   0.1242    0.1242   0.6210  PROD Tech PSPMAA0604-220M-ANP

1 board(s): parts per board USD 30.0355 = EUR 26.3979; order USD 60.5229 = EUR 53.1929
5 board(s): parts per board USD 28.4218 = EUR 24.9796; order USD 151.6200 = EUR 133.2572

Largest per-board contributors (1 board):
    3.8633 USD  12.9%  C716,C717,C718,C719,C726,C727,C728  Murata GRM32EC72A106KE05L
    3.7644 USD  12.5%  U201  Espressif ESP32-WROOM-32E-N4
    2.9304 USD   9.8%  L711  Bourns SRP1770TA-470M
    1.8784 USD   6.3%  U710,U720  Diodes AL8853S-13
    1.7574 USD   5.9%  C521,C710,C715,C725,C905,C906  Taiyo Yuden UMK325AB7106KMHP
    1.1226 USD   3.7%  L721  Bourns SRP1265A-470M
    0.8686 USD   2.9%  Q711,Q721  AOS AOD66923
    0.8670 USD   2.9%  C909  Panasonic 25SVPF100M
    0.8159 USD   2.7%  U902  TI LMR16020PDDAR
    0.8052 USD   2.7%  J501,J511  DORABO DB125-3.5-4P-GN-S
    0.7717 USD   2.6%  Q601  onsemi NTMFS5C628NLT1G
    0.7608 USD   2.5%  F501,F511,F521  Littelfuse 0451001.MRL

Per board by line kind (1 board): clone USD 0.4524, extra USD 0.1236, generic USD 0.3239, mpn USD 29.1356

Per board by schematic sheet (1 board):
   13.5179 USD  45.0%  LEDDrivers
    5.0747 USD  16.9%  InputPower
    3.9787 USD  13.2%  MCU / ESP32
    2.9292 USD   9.8%  Outputs
    2.0903 USD   7.0%  MCU / ESP32/Peripherals
    1.4314 USD   4.8%  Outputs/Heater
    0.8897 USD   3.0%  root
    0.1236 USD   0.4%  consumables

Stock shortfalls at the snapshot date:
  1 board(s): J901 C98732 stock 0, Amass XT60PW-M
  5 board(s): J901 C98732 stock 0, Amass XT60PW-M

Unpriced lines:
  (not in schematic) qty 1: CR2032 cell (BT301) - no CR2032 cell found at LCSC on the snapshot date; buy locally

Line notes:
  C106 [zero] not fitted
  C203,C302 [generic] 1u 25V X7R 0603 (JLC basic C15849 has 50 in stock)
  D301,D302,D501,D511 [clone] TI TPD2E2U06DCKR C1855726 has 0 in stock
  F301 [generic] PTC 100mA 60V 1206
  TP101,TP102,TP103,TP301,TP901,TP902 [zero] copper pad only
  NT711,NT712,NT721,NT722 [zero] copper only: Kelvin taps at the LED-driver shunts
  R201..R728 (19) [generic] 10k 1%
  R303..R521 (9) [generic] 33R also for the three GPIO gate resistors
  C712,C713,C722,C723 [generic] 100p C0G

170 of 170 schematic references covered; 3 zero-cost lines.

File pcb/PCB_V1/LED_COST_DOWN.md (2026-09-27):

> **Ревизия 0.14:** плата переведена на 24 В — см. [REDESIGN_24V.md](REDESIGN_24V.md). Этот документ описывает 12-вольтовую версию 0.12–0.13 и сохранён как история.

# LED и RTC: контроль стоимости, ревизия 0.13

Бюджет компонентов всей платы **около $30** — ориентир пользователя для контроля стоимости, не жёсткий предел. Сохраняем обоснованный электрический и тепловой запас. Полная стоимость ещё не подсчитана; плата не готова к изготовлению.

## Решение

В активном листе LEDDrivers три LT3756 заменены тремя AL8853S-13. Один общий boost с тремя buck-драйверами оставлен только рассмотренным вариантом: он требует дополнительной ступени преобразования и запаса напряжения для buck. Новый вариант сохраняет независимое ограничение тока и одну команду яркости.

По [datasheet AL8853](https://www.diodes.com/datasheet/download/AL8853.pdf): SO-8, VIN1/GATE2/GND3/CS4/FB5/COMP6/OVP7/PWM8; опорное напряжение FB 200 mV ±3%; частота преобразования 110–130 kHz. Вход 12 V подходит; предел VIN40 V не является пределом выходного напряжения boost. Выход задают нагрузка, внешние силовые детали и OVP.

PWM преобразуется во внутреннюю аналоговую уставку тока; это не прежнее прямое включение/выключение 48 V. Начальная команда 20 kHz, разрешённый диапазон 5–50 kHz. U700 объединяет LIGHT_PWM и LIGHT_ENABLE; три pull-down удерживают выключенное состояние при сбросе. Глубину регулирования, задержку выключения и отсутствие слабого свечения надо измерить. Источники: datasheet выше и [SN74LVC1G08](https://www.ti.com/lit/ds/symlink/sn74lvc1g08.pdf).

## Изменённые соединения

- Каждый LED+ подключён к выходу своего boost.
- Каждый LED− подключён к FB и верхнему выводу своего шунта; нижний вывод шунта — GND.
- **Нельзя соединять LED− между каналами или с GND.** Старое внешнее соединение ламп в одной точке требуется разобрать.
- Номиналы шунтов: R716=0.182 Ω/1%; R726/R736=0.80 Ω/1%. Расчётные токи 1.0989/0.25/0.25 A. При 48 V сумма 76.75 W; с +3% FB и −1% шунта около79.85 W. Это не гарантирует абсолютный предел80 W при выбросах, нагреве или Vf>48 V.
- R715=0.027 Ω/2 W; R725/R735=0.047 Ω/1 W, все 1%. R712=1k, R722/R732=2.7k, параллельно CS-GND100p. Расчёт токовой петли и ограничения OCP: [LED_POWER_COMPONENTS.md](LED_POWER_COMPONENTS.md).
- OVP:316k/10k, номинально65.2 V. При пороге1.9–2.1 V и резисторах1% приблизительно60.75–69.80 V. Все выходные силовые компоненты и конденсаторы рассчитаны на100 V; монтаж учитывать по аварийному напряжению, а не только48 V.

## Незакрытые расчёты

L711=47 µH SRP1770TA-470M; L721/L731=47 µH SRP1265A-470M. Дроссели, диоды STPS5H100B-TR / STPS2H100AFY и восемь Samsung CL32Y106KCV6PNE внесены в схему и PCB. Прежние placeholders заменены. [Подбор, размеры площадок и расчёты v0.12](LED_POWER_COMPONENTS.md).

Q711=SiR106ADP-T1-RE3 в PowerPAK_SO-8_Single. Q721/Q731=**TI CSD19538Q3A** в VSON 3,3×3,3 мм; DMT10H009LK3 из ревизии 0.10 исключён. В обоих footprints D-площадки объединены номером 5; G=4, S=1/2/3. Обоснование малых ключей и расчёт потерь: [MOSFET_SELECTION.md](MOSFET_SELECTION.md). [Q711](https://www.vishay.com/docs/77225/sir106adp.pdf): сопротивление до9 mΩ при7.5 V; при IQrms=5.446 A из расчёта v0.12 и условном росте сопротивления в1.7 раза потери проводимости около0.45 W. Фактические VGATE, фронты, нагрев и общий КПД предстоит измерить.

В расчёте v0.12 с допусками и снижением L под током пиковые рабочие токи до7.564/2.664/2.664 A. Проверено216 сочетаний условий, включая CCM/DCM; оценка OCP использует типовую рампу и не гарантирует отсечку во всех режимах. Исходные допущения и воспроизводимый скрипт приведены в новом документе. Isat проверяется относительно OCP, а не только номинального пика.

Компенсация10k/220n плюс100p — начальный вариант по структуре [оценочной платы AL8853EV1](https://www.diodes.com/assets/Evaluation-Boards/AL8853EV1-User-Guide.pdf), не подтверждённая устойчивость нашего каскада. Прямой путь VIN–L–диод сохраняется при shutdown; выключение GATE не отключает ток короткого замыкания выхода. Нужны защита каждой ветви и проверка предохранителей до выпуска платы.

## Цена, проверено 2026-09-27

Розничные отображаемые цены USD, ступень1+, без доставки, налогов, PCB, монтажа, SD-карты и внешнего БП; не фиксированное коммерческое предложение.

| Позиция | Количество | Цена за штуку | Сумма | Источник |
|---|---:|---:|---:|---|
| AL8853S-13, текущий | 3 | 0.9392 | 2.8176 | [LCSC C3192318](https://www.lcsc.com/product-detail/C3192318.html) |
| LT3756EMSE-2#TRPBF, исключён | 3 | 6.1131 | 18.3393 | [LCSC C462635](https://www.lcsc.com/product-detail/C462635.html) |
| ESP32-WROOM-32E-N4 | 1 | 3.7644 | 3.7644 | [LCSC C701341](https://www.lcsc.com/product-detail/C701341.html) |
| DS3231MZ+TRL, текущий | 1 | 3.2976 | 3.2976 | [LCSC C107410](https://www.lcsc.com/product-detail/C107410.html) |
| CSD19538Q3A, текущие Q721/Q731 | 2 | 1.0754 | 2.1508 | [LCSC C478471](https://www.lcsc.com/product-detail/C478471.html) |

Сумма четырёх текущих строк — **$12,0304**; исключённый LT3756 не учитывается. Добавленные в v0.12 цены дросселей, диодов и восьми выходных MLCC дают ещё **$13,8592**, см. [детальную таблицу](LED_POWER_COMPONENTS.md). В ревизии 0.12 было оценено 21 из 171 компонентов на $25,8896. В v0.13 цены LM74700, двух NTMFS5C628NL (Q901 и ранее не оценённого Q601) и TPS70950 добавляют $3,9014: **25 из 175 компонентов на $29,7910**. Остальные 150 ещё не оценены; полная плата будет дороже. [Цены входного узла и питания драйвера](INPUT_PROTECTION.md#стоимость-и-незавершённый-подбор). Это не стоимость полной платы и не заказной BOM. Для RTC и TI использованы открытые карточки товаров, а не устаревшие цены поискового кэша.

Замена контроллеров LT3756 → AL8853 ранее снизила цену самих контроллеров примерно на $15,52. Текущее изменение DS3231SN# ($10,0522) → DS3231MZ+TRL ($3,2976) и двух DMT ($1,3242/шт.) → TI ($1,0754/шт.) даёт ещё **$7,2522 экономии** относительно ревизии 0.10. Обвязка учитывается отдельно.

## RTC: исправление прежнего утверждения

**DS3231MZ+TRL совместим с текущими операциями RTC без изменения кода и принципа батарейного питания.** Адрес `0x68`, формат времени и OSF в `0x0F`/бит7 сохранены; CR2032 непосредственно питает VBAT без зарядки. Меняются символ, физические номера выводов и корпус SOIC-16W → SOIC-8. Утверждение, что такая замена обязательно требует другой прошивки и батарейной схемы, было неверным.

Учтён компромисс точности: у DS3231M ±5 ppm. Отличия неиспользуемых SQW/32kHz не влияют на текущий проект. Сверка используемых регистров, распиновки и ссылок на прошивку: [RTC_COMPATIBILITY.md](RTC_COMPATIBILITY.md).

## Проверки

ERC 0 ошибок/0 предупреждений. Проверки: 117 групп соединений, 15 назначений GPIO, изоляция трёх LED-return, VBAT и NC диода, аппаратный AND; 175 компонентов и 470 выводов netlist соответствуют PCB. PCB пока содержит компоненты в зоне подготовки вне контура100×100 mm; размещение и трассировка не выполнены. Проверки электрических цепей не подтверждают аналоговую устойчивость, тепловой режим или пригодность для производства.

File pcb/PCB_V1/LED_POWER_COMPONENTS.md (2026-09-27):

> **Ревизия 0.14:** плата переведена на 24 В — см. [REDESIGN_24V.md](REDESIGN_24V.md). Этот документ описывает 12-вольтовую версию 0.12–0.13 и сохранён как история.

# LED: силовые детали и расчёт v0.12

Расчёт и отчёты этого документа зафиксированы для v0.12. LED-каскад сохранён в v0.13; актуальные количество компонентов, общий ценовой итог и проверки всей платы — в [README](README.md) и [расчёте входного узла](INPUT_PROTECTION.md).

В схему и PCB внесены конкретные дроссели, выпрямители и выходные MLCC для трёх AL8853. Это подбор для прототипа: устойчивость внешней петли, пуск, аварийные режимы и температура ещё не подтверждены. PCB остаётся без размещения и трассировки. Токи LED сохранены: 1,099 / 0,25 / 0,25 А, одна команда яркости.

## Выбранные детали

| Ref | Деталь | Параметры, использованные при выборе | Footprint KiCad |
|---|---|---|---|
| L711 | Bourns SRP1770TA-470M | 47 µH ±20%; DCR max 55 mΩ; Irms 8,7 A; Isat 9,5 A при −20% L / 16 A при −30% L | Inductor_SMD:L_Bourns_SRP1770TA_16.9x16.9mm |
| L721/L731 | Bourns SRP1265A-470M | 47 µH ±20%; DCR max 90 mΩ; Irms 6,5 A; Isat 9,5 A при −20% L | GrowBox:L_Bourns_SRP1265A |
| D711 | ST STPS5H100B-TR | 100 V; 5 A average / 10 A RMS при условиях datasheet; DPAK | Package_TO_SOT_SMD:TO-252-2 |
| D721/D731 | ST STPS2H100AFY | 100 V; 2 A average при TL=150°C и δ=0,5; SOD128Flat | Diode_SMD:D_SOD-128 |
| C716–C719, C726/C727, C736/C737 | Samsung CL32Y106KCV6PNE | 10 µF, 100 V, X7S, ±10%, 1210; 4 / 2 / 2 шт. по каналам | Capacitor_SMD:C_1210_3225Metric |

Irms дросселей задан при подъёме температуры на 40°C в условиях производителя. Это не допустимый ток в любом корпусе гроубокса. Isat также не заменяет проверку при высокой температуре. Для SRP1265A создано проектное посадочное место: площадки 3,1×5,0 мм, центры ±5,55 мм; механика 13,5×12,5 мм, высота 6,2±0,3 мм. Неподходящая модель высоты SRP1245A удалена. Площадки L711 — 3,15×12,5 мм, центры ±7,675 мм.

У D711 **1=NC, 2=K/tab, 3=A**. Использован отдельный проектный символ; NC не соединён с медью других цепей. Рисунок выводов сверён по ST DocID5388 Rev12, стр.1, доступному у RS; предельные параметры и размеры — по актуальному Rev13. Назначен стандартный KiCad TO-252-2 с шагом выводов 2,28 мм, боковыми площадками 2,2×1,2 мм и tab 6,4×5,8 мм. Это стандартный land pattern KiCad, а не копия увеличенной рекомендации ST. Проверить паяный образец и отвод тепла через катодную площадку. У SOD128 катодная метка соответствует pad1; площадки 1,4×2,1 мм, центры ±2,2 мм совпадают с рекомендацией ST, стр.10.

Первичные источники:

- [Bourns SRP1770TA](https://www.bourns.com/docs/Product-Datasheets/SRP1770TA.pdf), таблица 470M и рекомендуемый монтаж.
- [Bourns SRP1265A](https://www.bourns.com/docs/Product-Datasheets/SRP1265A.pdf), таблица 470M и рекомендуемый монтаж.
- [STPS5H100, Rev13](https://www.st.com/resource/en/datasheet/stps5h100.pdf); [документ ST Rev12 у RS](https://docs.rs-online.com/cad8/0900766b8097a825.pdf).
- [STPS2H100-Y, Rev2](https://www.st.com/resource/en/datasheet/stps2h100-y.pdf); [тот же документ у RS](https://docs.rs-online.com/4857/A700000008082376.pdf).

## Что изменено в малых каналах

L721/L731: прежнее требование 100 µH заменено конкретными 47 µH. Одновременно R725/R735 изменены с 0,10 на **0,047 Ω / 1% / ≥1 W**, R722/R732 с 1k на **2,7k / 1%**. Большой канал: R715=0,027 Ω / 1% / ≥2 W, R712=1k / 1%. Все три CS-конденсатора остаются 100 pF. Эти резисторы относятся к пиковому току ключа и slope compensation; ток LED по-прежнему задают отдельные R716=0,182 Ω и R726/R736=0,80 Ω.

По [AL8853](https://www.diodes.com/datasheet/download/AL8853.pdf), для предварительного расчёта токовой петли использованы:

```text
Sn = Rs × Vin / L
Sf = Rs × (Vo − Vin) / L
Se = (VSL + Is × Rsl) × fs
CCM screening: abs((Sf − Se)/(Sn + Se)) < 1
VSL=100 mV, Is=50 µA — типовые значения, не гарантированные границы.
```

Порог CS 255…345 mV специфицирован при duty 90%. Приведённые ниже OCP — оценка при рабочем duty и типовой компенсационной рампе, **не гарантированный диапазон отсечки**. Запас большого канала над рабочим пиком всего около 0,34 А в худшей паре расчётных условий. Нужны измерения: допуски рампы, задержка выключения и звон CS могут изменить результат. Внешняя RC-компенсация 10k/220n + 100p оставлена предварительной; проверка субгармоник не подтверждает устойчивость внешней петли.

## Воспроизводимые оценки

Скрипт `../analyze_led_power.py` сначала сверяет новые номиналы/MPN с экспортированным XML, затем перебирает 72 режима на канал: Vin=10,8/12/13,2 V непосредственно на LED-шине, Vf=40/44/48 V, fs=110/130 kHz, принятый КПД 85/90%, номинальный и +3% FB/−1% LED-шунт. Это расчётный диапазон для внешнего 12 V БП, не расширение входа до 24 V.

Для оценки токов идеальный каскад нагружен током ILED/η; Vo включает FB и падение диода. Такой подход намеренно завышает нагрузку; он не предсказывает фактический КПД, duty или распределение потерь. Учтён переход в DCM. L взята с −20% начальным допуском и дополнительным снижением на 30% для большого / 20% для малых дросселей. Оценка сопротивления обмотки относится к 100°C.

| Расчётная величина | Большой канал | Каждый малый |
|---|---:|---:|
| Рабочий пиковый ток L, max | 7,564 A | 2,664 A |
| RMS ток L / ключа / диода, max | 6,167 / 5,446 / 2,894 A | 1,573 / 1,389 / 0,738 A |
| Коэффициент субгармоник, max, CCM | 0,839 | 0,812 |
| Оценка OCP при рабочих duty | 7,907…12,479 A | 3,131…6,625 A |
| Минимальный запас OCP над пиком в том же режиме | 0,343 A | 0,468 A |
| Потери меди обмотки при 100°C, max | 2,708 W | 0,288 W |
| Потери CS-шунта, max | 0,809 W | 0,092 W |
| Потери проводимости диода, оценка max | 0,853 W | 0,196 W |

Не включены потери сердечника, горячее насыщение, обратный ток и динамические потери диодов, потери переключения MOSFET и нагрев от соседних деталей. Поэтому таблица не подтверждает общий КПД и не заменяет тепловой расчёт. Главный дроссель потребует заметной площади и свободного отвода тепла.

Суммарная мощность LED при 48 V: 76,75 W номинально / 79,85 W на учтённой границе FB и LED-шунтов. Это статическая оценка, без гарантии абсолютного потолка 80 W при переходных процессах или Vf>48 V.

## Выходная ёмкость под напряжением

На [официальной странице Samsung](https://product.samsungsem.com/mlcc/CL32Y106KCV6PN.do) типовая DC-bias кривая при 25°C показывает для одного номинального 10 µF конденсатора около **2,647 µF при 48 V**, 2,575 µF при 49 V и 1,591 µF при 70 V. Поэтому прежнее требование «≥4,7 µF на каждый при 48 V» для этого MPN невыполнимо. Оно заменено расчётом всей батареи конденсаторов; два дополнительных C718/C719 установлены в большом канале.

Консервативное расчётное допущение: 2,575 µF × 0,90 (начальный допуск) × 0,78 (X7S) × 0,90 (дополнительный запас на старение/модель) = **1,627 µF на деталь**. Последние множители не превращают типовую DC-bias кривую в гарантированный минимум при одновременном воздействии всех факторов. Для выпуска нужна проверка эффективной ёмкости и нагрева реальной партии.

Получается 6,508 / 3,254 / 3,254 µF на канал. Грубая верхняя оценка полного разряда за один цикл `ILED/(fs×C)` даёт 1,597 / 0,727 / 0,727 Vpp при 110 kHz. ESR/ESL, переходные процессы и звон кабеля сюда не входят. RMS-ток батареи по расчёту — до 2,562 / 0,671 / 0,671 A; при равном распределении около 0,64 / 0,34 / 0,34 A на корпус. Проверить распределение токов и нагрев на реальном layout. На OVP ёмкость ещё ниже; пуск и обрыв нагрузки требуют отдельного измерения.

## Цена выбранных силовых деталей

Снимок LCSC 2026-09-27, USD, ступень 1+, без доставки/налогов. Остатки изменяются; это не заказ.

| Деталь | Количество | Цена за шт. | Сумма | Карточка / доступный остаток |
|---|---:|---:|---:|---|
| SRP1770TA-470M | 1 | 2,9304 | 2,9304 | [C2041872](https://www.lcsc.com/product-detail/C2041872.html), 26 |
| SRP1265A-470M | 2 | 1,1226 | 2,2452 | [C840530](https://www.lcsc.com/product-detail/C840530.html), 3895; обычная цена без акции |
| STPS5H100B-TR | 1 | 0,5802 | 0,5802 | [C10648](https://www.lcsc.com/product-detail/C10648.html), 2249 |
| STPS2H100AFY | 2 | 0,4753 | 0,9506 | [C3757915](https://www.lcsc.com/product-detail/C3757915.html), 224 |
| CL32Y106KCV6PNE | 8 | 0,8941 | 7,1528 | [C22380050](https://www.lcsc.com/product-detail/C22380050.html), 16517 |

Новая оценённая группа: **$13,8592**. Вместе с прежними 7 оценёнными деталями ($12,0304) получается **$25,8896 за 21 из 171 компонентов**. Остальные 150 ещё не оценены: это не цена полной платы и не обещание уложиться в $30. Например, покупка 10 MLCC по $0,7219 стоит $7,219 и оставляет две запасные детали; стоимость покупки и стоимость установленных компонентов учитывать отдельно. Бюджет $30 остаётся ориентиром, установленным пользователем.

## Проверки и дальнейшая работа

- ERC: 0 ошибок, 0 предупреждений; новых исключений нет.
- Netlist: 111 групп, 15 GPIO, изоляция LED-return/VBAT/NC; 171 компонент, 455 узлов.
- Все значения и полные библиотечные идентификаторы footprint совпадают со схемой. Восстановлены потерянные при старом импорте префиксы 162 библиотечных ссылок; геометрия этих деталей не менялась.
- DRC: 12 прежних ошибок сверления 0,20 mm в ESP32 при правиле 0,30 mm; 366 соединений не разведены. Новых ошибок геометрии выбранных деталей нет.
- Отчёты: `../review/ERC_v12.rpt`, `DRC_staging_v12.rpt`, `LED_power_v12.txt`; просмотр схемы: `LEDDrivers_v12.png`.

Следующие обязательные узлы: защита каждой LED-ветви от КЗ с учётом прямого пути VIN–L–D при выключенном boost, входной силовой MOSFET/предохранители/клеммы и согласование защиты VDD UCC27524A. До изготовления также нужны input-cap MPN/derating, компенсация, ограничение VGS при выбросах, размещение, трассировка и стендовая программа испытаний. Отключение PWM само по себе не разрывает аварийный ток через дроссель и диод.

Воспроизведение из каталога `pcb`:

```text
kicad-cli sch export netlist --format kicadxml -o netlist.xml PCB_V1/PCB_V1.kicad_sch
python verify_netlist.py netlist.xml
python analyze_led_power.py netlist.xml --output review/LED_power_v12.txt
python verify_board.py netlist.xml PCB_V1/PCB_V1.kicad_pcb
python export_bom.py netlist.xml PCB_V1/BOM_schematic.csv
```

`verify_board.py` запускать Python, поставляемым с KiCad. Остальным Python-скриптам достаточно стандартной библиотеки. ERC/DRC запускать также через `kicad-cli`; они проверяют соединения/правила, но не работоспособность преобразователей.

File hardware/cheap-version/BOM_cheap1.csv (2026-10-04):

Line | Designators | Qty | Value | Footprint | Manufacturer | MPN | LCSC | Source | From stock | To buy | Stock note
1 | BT301 | 1 | CR2032 / NO CHARGE | BatteryHolder_MYOUNG_BS-07-A1BJ001_CR2032 | MYOUNG | BS-07-A1BJ001 | C2979167 | buy | 0 | 1
2 | BT301 | 1 | CR2032 cell |  |  | CR2032 |  | buy | 0 | 1
3 | C101 C602 C910 | 3 | 10u 35V X5R | C_1210_3225Metric | Samsung Electro-Mechanics | CL32A106KLULNNE | C2980162 | stock:6 | 3 | 0 | id 6: 8 in stock, 3 used
4 | C102 C202 C301 C303 C402 C601 C700 C907 C908 C911 | 10 | 100n 50V X7R | C_0603_1608Metric | Samsung | CL10B104KB8NNNC | C1591 | stock:54 | 10 | 0 | id 54: 23 in stock, 10 used
5 | C103 C203 C302 | 3 | 2.2u 16V X5R | C_0805_2012Metric | Samsung Electro-Mechanics | CL21A225KOFNNNE |  | stock:57 | 3 | 0 | id 57: 18 in stock, 3 used
6 | C104 C105 C401 | 3 | 22u / 10V X5R | C_0805_2012Metric | Samsung Electro-Mechanics | CL21A226KPCLRNC | C318688 | stock:7 | 3 | 0 | id 7: 9 in stock, 3 used
7 | C201 | 1 | 10u 16V X5R | C_0805_2012Metric | Samsung Electro-Mechanics | CL21A106KAYNNNE | C15850 | stock:58 | 1 | 0 | id 58: 7 in stock, 1 used
8 | C304 | 1 | 18p 50V C0G | C_0603_1608Metric | Samsung | CL10C180JB8NNNC | C1647 | buy | 0 | 1
9 | C521 | 1 | 10u / 50V X7R | C_1210_3225Metric | Samsung Electro-Mechanics | CL32B106KBJNNNE | C92388 | stock:47 | 1 | 0 | id 47: 6 in stock, 6 used (no spare)
10 | C710 C715 C725 C905 C906 | 5 | 10u 50V X7R | C_1210_3225Metric | Samsung Electro-Mechanics | CL32B106KBJNNNE | C92388 | stock:47 | 5 | 0 | id 47: 6 in stock, 6 used (no spare)
11 | C711 C721 C902 | 3 | 2.2u 50V X7R | C_1206_3216Metric | KYOCERA AVX | 12065C225KATM-HW |  | stock:3 | 3 | 0 | id 3: 9 in stock, 3 used
12 | C712 C713 C722 C723 | 4 | 100p | C_0603_1608Metric | Samsung | CL10C101JB8NNNC | C14858 | buy | 0 | 4
13 | C714 C724 | 2 | 220n | C_0603_1608Metric | Samsung | CL10B224KB8NNNC | C64705 | buy | 0 | 2
14 | C716 C717 C718 C719 C726 C727 C728 | 7 | 10u 100V X7S | C_1210_3225Metric | Murata | GRM32EC72A106KE05L | C576517 | buy | 0 | 7
15 | C901 | 1 | 470u / 63V | CP_Elec_16x17.5 | Panasonic | EEVFK1J471M | C178728 | stock:13 | 1 | 0 | id 13: 1 in stock, 1 used (no spare)
16 | C909 | 1 | 820u 25V | CP_Elec_10x10.5 | Panasonic | EEEFT1E821AP | C178593 | stock:14 | 1 | 0 | id 14: 1 in stock, 1 used (no spare)
17 | D301 D302 D501 D511 | 4 | TPD2E2U06DCKR | SOT-323_SC-70 | TECH PUBLIC | TPD2E2U06DCKR-TP | C5350871 | buy | 0 | 4
18 | D303 | 1 | BAV170 | SOT-23 | JSCJ | BAV170 | C68970 | buy | 0 | 1
19 | D521 D902 | 2 | SS56 | D_SMC |  | SS56 |  | stock:20 | 2 | 0 | id 20: 45 in stock, 2 used
20 | D601 D901 | 2 | SMBJ26CA-E3/52 | D_SMB | Vishay | SMBJ26CA-E3/52 | C515606 | buy | 0 | 2
21 | D711 D721 | 2 | SBRT15U100SP5 | Diodes_PowerDI5 | Diodes Incorporated | SBRT15U100SP5-13 | C2934601 | stock:8 | 2 | 0 | id 8: 5 in stock, 2 used
22 | F301 | 1 | PTC 0.10A / >=16V | Fuse_1206_3216Metric | TECHFUSE | nSMD010 | C70065 | buy | 0 | 1
23 | F501 F511 F521 | 3 | 1A / 0451001.MRL | Fuse_Littelfuse_451 | Littelfuse | 0451001.MRL | C3099 | buy | 0 | 3
24 | F711 | 1 | 6.3A / 045106.3MRL | Fuse_Littelfuse_451 | Littelfuse | 045106.3MRL | C178982 | buy | 0 | 1
25 | F721 F904 | 2 | 3A / 0451003.MRL | Fuse_Littelfuse_451 | Littelfuse | 0451003.MRL | C13982 | buy | 0 | 2
26 | F902 | 1 | 10A mini blade (ATM) | Fuseholder_Blade_Mini_XFCN_XF-508P | XFCN | XF-508P-B-B | C19727305 | buy | 0 | 1
27 | J201 | 1 | UART / 3V3 logic | PinHeader_1x06_P2.54mm_Vertical | BOOMELE | 2.54-1x6P | C37208 | buy | 0 | 1
28 | J301 | 1 | SHT4x / XH 2.50 | JST_XH_S4B-XH-A_1x04_P2.50mm_Horizontal |  | XH2.54-4P-90 |  | stock:90 | 1 | 0 | id 90: 60 in stock, 1 used
29 | J302 | 1 | FLOAT / 3.5 mm | TerminalBlock_Phoenix_PT-1,5-2-3.5-H_1x02_P3.50mm_Horizontal |  | FS1.5-02-350-2601R |  | stock:86 | 1 | 0 | id 86: 7 in stock, 3 used
30 | J401 | 1 | HRO TF-01A | microSD_HRO_TF-01A | Korean Hroparts Elec | TF-01A | C91145 | buy | 0 | 1
31 | J501 | 1 | FAN1 / 3.5 mm | Molex_KK-254_AE-6410-04A_1x04_P2.54mm_Vertical |  | KF2510-4P |  | stock:87 | 1 | 0 | id 87: 9 in stock, 2 used
32 | J511 | 1 | FAN2 / 3.5 mm | Molex_KK-254_AE-6410-04A_1x04_P2.54mm_Vertical |  | KF2510-4P |  | stock:87 | 1 | 0 | id 87: 9 in stock, 2 used
33 | J521 | 1 | PUMP 24V / 6W | TerminalBlock_Phoenix_PT-1,5-2-3.5-H_1x02_P3.50mm_Horizontal |  | FS1.5-02-350-2601R |  | stock:86 | 1 | 0 | id 86: 7 in stock, 3 used
34 | J601 | 1 | PTC + / switched - (3.5 mm) | TerminalBlock_Phoenix_PT-1,5-2-3.5-H_1x02_P3.50mm_Horizontal |  | FS1.5-02-350-2601R |  | stock:86 | 1 | 0 | id 86: 7 in stock, 3 used
35 | J711 J721 J731 | 3 | LED +/- (return isolated) | TerminalBlock_Phoenix_MKDS-1,5-2_1x02_P5.00mm_Horizontal |  | KF301-5.0-2P |  | stock:93 | 3 | 0 | id 93: 31 in stock, 4 used
36 | J901 | 1 | 24V IN (KF301-5.0-2P) | TerminalBlock_KF301_1x02_P5.00mm_Horizontal_Input |  | KF301-5.0-2P |  | stock:93 | 1 | 0 | id 93: 31 in stock, 4 used
37 | L101 | 1 | 4.7u FXL0630-4R7-M | L_Changjiang_FXL0630 | cjiang | FXL0630-4R7-M | C167220 | buy | 0 | 1
38 | L711 | 1 | 47u DTMSS-27/0.047/15-V | L_Feryster_DTMSS-27_V | Feryster | DTMSS-27/0.047/15-V |  | stock:12 | 1 | 0 | id 12: 1 in stock, 1 used (no spare)
39 | L721 | 1 | 47u SRP1265A-470M | L_Bourns_SRP1265A | Bourns | SRP1265A-470M | C840530 | buy | 0 | 1
40 | L902 | 1 | 22u PSPMAA0604-220M | L_Changjiang_FXL0630 | PROD Tech | PSPMAA0604-220M-ANP | C53190553 | buy | 0 | 1
41 | Q501 Q511 | 2 | AO3400A | SOT-23 | AOS | AO3400A | C20917 | buy | 0 | 2
42 | Q521 | 1 | AO3422 | SOT-23 | AOS | AO3422 | C37130 | buy | 0 | 1
43 | Q601 | 1 | IRL2505 | TO-220-3_Vertical |  | IRL2505 |  | stock:78 | 1 | 0 | id 78: 1 in stock, 1 used (no spare)
44 | Q711 Q721 | 2 | BSC146N10LS5 | TDSON-8-1 | Infineon Technologies | BSC146N10LS5 |  | stock:112 | 2 | 0 | id 112: 2 in stock, 2 used (no spare)
45 | R101 R502 R512 R522 R602 R713 R723 | 7 | 100k 1% | R_0603_1608Metric | Yageo | RC0603FR-07100KL | C14675 | stock:55 | 7 | 0 | id 55: 14 in stock, 7 used
46 | R102 | 1 | 31.6k 1% | R_0603_1608Metric | UNI-ROYAL | 0603WAF3162T5E | C25967 | buy | 0 | 1
47 | R201 R202 R203 R207 R208 R209 R210 R211 R212 R306 R405 R406 R407 R408 R410 R714 R724 | 17 | 10k 5% | R_0805_2012Metric | UNI-ROYAL | 0603WAF1002T5E | C25804 | stock:70 | 17 | 0 | id 70: 85 in stock, 17 used
48 | R204 R205 R206 R305 R307 R503 R513 R712 | 8 | 1k 1% | R_0603_1608Metric | Yageo | RC0603FR-071KL | C21190 | stock:62 | 8 | 0 | id 62: 14 in stock, 8 used
49 | R301 R302 | 2 | 4.7k 5% | R_0805_2012Metric | UNI-ROYAL | 0603WAF4701T5E | C23162 | stock:72 | 2 | 0 | id 72: 85 in stock, 2 used
50 | R303 R304 R401 R402 R403 R404 R501 R511 R521 | 9 | 33 | R_0603_1608Metric | UNI-ROYAL | 0603WAF330JT5E | C23140 | buy | 0 | 9
51 | R601 R711 R721 | 3 | 10R 5% | R_1206_3216Metric | UNI-ROYAL | 0603WAF100JT5E | C22859 | stock:41 | 3 | 0 | id 41: 5 in stock, 3 used
52 | R703 R908 | 2 | 47k 1% | R_1206_3216Metric | Yageo | RC0603FR-0747KL | C105579 | stock:61 | 2 | 0 | id 61: 6 in stock, 2 used
53 | R715 | 1 | 0.027 1% >=1W | R_2512_6332Metric | UNI-ROYAL | LR123WF270MT4E | C19633795 | buy | 0 | 1
54 | R716 | 1 | 0.12 1% 3W 50ppm | R_2512_6332Metric | JIERR | JER2512F3R120 | C49164917 | buy | 0 | 1
55 | R717 R727 | 2 | 316k 1% | R_0603_1608Metric | UNI-ROYAL | 0603WAF3163T5E | C25814 | buy | 0 | 2
56 | R718 R728 | 2 | 10k 1% | R_0805_2012Metric | UNI-ROYAL | 0603WAF1002T5E | C25804 | stock:59 | 2 | 0 | id 59: 19 in stock, 2 used
57 | R722 | 1 | 2.7k 1% | R_0603_1608Metric | UNI-ROYAL | 0603WAF2701T5E | C13167 | buy | 0 | 1
58 | R725 | 1 | 0.047 1% >=1W | R_2512_6332Metric | RVR | HIXD25NR047F | C52015951 | buy | 0 | 1
59 | R726 | 1 | 0.43 1% >=0.25W | R_1206_3216Metric | TA-I | RLH12FTCR430 | C22464907 | buy | 0 | 1
60 | R904 | 1 | 88.7k 0.1% | R_0603_1608Metric | Yageo | RT0603BRD0788K7L | C728599 | buy | 0 | 1
61 | R905 | 1 | 10k 0.1% | R_0603_1608Metric | Yageo | RT0603BRD0710KL | C95204 | buy | 0 | 1
62 | R907 | 1 | 470k 1% | R_0603_1608Metric | UNI-ROYAL | 0603WAF4703T5E | C23178 | buy | 0 | 1
63 | SW201 | 1 | RESET | SW_PUSH_6mm_H9.5mm |  | 6X6X10MM Tact Switch |  | stock:95 | 1 | 0 | id 95: 15 in stock, 2 used
64 | SW202 | 1 | BOOT | SW_PUSH_6mm_H9.5mm |  | 6X6X10MM Tact Switch |  | stock:95 | 1 | 0 | id 95: 15 in stock, 2 used
65 | U101 | 1 | ST1S10PHR | SOIC-8-1EP_3.9x4.9mm_P1.27mm_EP2.41x3.3mm | STMicroelectronics | ST1S10PHR | C11175 | stock:27 | 1 | 0 | id 27: 4 in stock, 1 used
66 | U201 | 1 | ESP32-WROOM-32E-N4 | ESP32-WROOM-32E_NoVias | Espressif | ESP32-WROOM-32E-N4 | C701341 | buy | 0 | 1
67 | U301 | 1 | PCF8563T/5 | SOIC-8_3.9x4.9mm_P1.27mm | NXP | PCF8563T/5,518 | C7440 | buy | 0 | 1
68 | U601 | 1 | UCC27524ADR | SOIC-8_3.9x4.9mm_P1.27mm | TI | UCC27524ADR | C185857 | buy | 0 | 1
69 | U700 | 1 | SN74LVC1G08DBVR | SOT-23-5 | TI | SN74LVC1G08DBVR | C7666 | buy | 0 | 1
70 | U710 U720 | 2 | AL8853S-13 | SOIC-8_3.9x4.9mm_P1.27mm | Diodes | AL8853S-13 | C3192318 | buy | 0 | 2
71 | U902 | 1 | ST1S14PHR | SOIC-8-1EP_3.9x4.9mm_P1.27mm_EP2.41x3.3mm | STMicroelectronics | ST1S14PHR | C84130 | stock:26 | 1 | 0 | id 26: 3 in stock, 1 used
72 | Y301 | 1 | 32.768k 12.5pF | Crystal_SMD_3215-2Pin_3.2x1.5mm | Epson | Q13FC13500004 | C32346 | buy | 0 | 1

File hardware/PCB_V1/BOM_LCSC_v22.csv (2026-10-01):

Quantity | LCSC Part Number | Manufacturer Part Number | Manufacturer | Description | Customer Part Number
1 | C191884 | TPS54202DDCR | TI | TI TPS54202DDCR | U101
1 | C701341 | ESP32-WROOM-32E-N4 | Espressif | Espressif ESP32-WROOM-32E-N4 | U201
1 | C7440 | PCF8563T/5,518 | NXP | NXP PCF8563T/5,518 | U301
1 | C185857 | UCC27524ADR | TI | TI UCC27524ADR | U601
1 | C7666 | SN74LVC1G08DBVR | TI | TI SN74LVC1G08DBVR | U700
2 | C3192318 | AL8853S-13 | Diodes | Diodes AL8853S-13 | U710 U720
1 | C190006 | LMR16020PDDAR | Texas Instruments | Texas Instruments LMR16020PDDAR | U902
2 | C20917 | AO3400A | AOS | AOS AO3400A | Q501 Q511
1 | C37130 | AO3422 | AOS | AOS AO3422 | Q521
1 | C145537 | NTMFS5C628NLT1G | onsemi | onsemi NTMFS5C628NLT1G | Q601
2 | C485687 | AOD66923 | AOS | AOS AOD66923 | Q711 Q721
4 | C5350871 | TPD2E2U06DCKR-TP | TECH PUBLIC | TECH PUBLIC TPD2E2U06DCKR-TP | D301 D302 D501 D511
1 | C68970 | BAV170 | JSCJ | JSCJ BAV170 | D303
2 | C35722 | SS36-E3/57T | Vishay | Vishay SS36-E3/57T | D521 D902
2 | C515606 | SMBJ26CA-E3/52 | Vishay | Vishay SMBJ26CA-E3/52 | D601 D901
2 | C46986 | SS5P10-M3/86A | Vishay | Vishay SS5P10-M3/86A | D711 D721
1 | C167223 | FXL0630-100-M | cjiang | cjiang FXL0630-100-M | L101
1 | C2041872 | SRP1770TA-470M | Bourns | Bourns SRP1770TA-470M | L711
1 | C840530 | SRP1265A-470M | Bourns | Bourns SRP1265A-470M | L721
1 | C53190553 | PSPMAA0604-220M-ANP | PROD Tech | PROD Tech PSPMAA0604-220M-ANP | L902
2 | C309062 | CL32B226KAJNNNE | Samsung | 22u 25V X7R 1210 | C101 C910
10 | C1591 | CL10B104KB8NNNC | Samsung | 100n 50V X7R 0603 | C102 C103 C202 C301 C303 C402 C601 C700 C907 C908
3 | C29277 | CL21A226MPQNNNE | Samsung Electro-Mechanics | 22u / 10V X5R 0805 | C104 C105 C401
2 | C15850 | CL21A106KAYNNNE | Samsung Electro-Mechanics | 10u / 25V X5R 0805 | C201 C602
2 | C29936 | CL10B105KA8NNNC | Samsung | 1u / 16V 0603 | C203 C302
1 | C1647 | CL10C180JB8NNNC | Samsung | 18p 50V C0G 0603 | C304
6 | C386166 | UMK325AB7106KMHP | Taiyo Yuden | 10u 50V X7R 1210 | C521 C710 C715 C725 C905 C906
2 | C28323 | CL21B105KBFNNNE | Samsung | 1u 50V X7R 0805 | C711 C721
4 | C14858 | CL10C101JB8NNNC | Samsung | 100p 0603 | C712 C713 C722 C723
2 | C64705 | CL10B224KB8NNNC | Samsung | 220n 0603 | C714 C724
7 | C576517 | GRM32EC72A106KE05L | Murata | 10u 100V X7S 1210 | C716 C717 C718 C719 C726 C727 C728
1 | C178549 | EEEFK1H221P | Panasonic | 220u / 50V CP_Elec_10x10.5 | C901
1 | C40708 | CL32B105KBHNNNE | Samsung Electro-Mechanics | 1u / 50V X7R 1210 | C902
1 | C136279 | 25SVPF100M | Panasonic | 100u 25V polymer CP_Elec_8x6.9 | C909
7 | C25803 | 0603WAF1003T5E | UNI-ROYAL | 100k 1% 0603 | R101 R502 R512 R522 R602 R713 R723
1 | C31850 | 0603WAF2202T5E | UNI-ROYAL | 22k 1% 0603 | R102
19 | C25804 | 0603WAF1002T5E | UNI-ROYAL | 10k 0603 | R201 R202 R203 R207 R208 R209 R210 R211 R212 R306 R405 R406 R407 R408 R410 R714 R718 R724 R728
8 | C21190 | 0603WAF1001T5E | UNI-ROYAL | 1k 1% 0603 | R204 R205 R206 R305 R307 R503 R513 R712
2 | C23162 | 0603WAF4701T5E | UNI-ROYAL | 4.7k 0603 | R301 R302
9 | C23140 | 0603WAF330JT5E | UNI-ROYAL | 33 0603 | R303 R304 R401 R402 R403 R404 R501 R511 R521
3 | C22859 | 0603WAF100JT5E | UNI-ROYAL | 10R 0603 | R601 R711 R721
3 | C105579 | RC0603FR-0747KL | Yageo | 47k 1% 0603 | R703 R906 R908
1 | C19633795 | LR123WF270MT4E | UNI-ROYAL | 0.027 1% >=1W 2512 | R715
1 | C48533605 | FRM252WFR180TM | FOJAN | 0.18 1% 2W 50ppm 2512 | R716
2 | C25814 | 0603WAF3163T5E | UNI-ROYAL | 316k 1% 0603 | R717 R727
1 | C13167 | 0603WAF2701T5E | UNI-ROYAL | 2.7k 1% 0603 | R722
1 | C52015951 | HIXD25NR047F | RVR | 0.047 1% >=1W 2512 | R725
1 | C22464907 | RLH12FTCR430 | TA-I | 0.43 1% >=0.25W 1206 | R726
1 | C326734 | RT0603BRD07150KL | Yageo | 150k 0.1% 0603 | R904
1 | C95204 | RT0603BRD0710KL | Yageo | 10k 0.1% 0603 | R905
1 | C23203 | 0603WAF5603T5E | UNI-ROYAL | 560k 1% 0603 | R907
1 | C70065 | nSMD010 | TECHFUSE | TECHFUSE nSMD010 | F301
3 | C3099 | 0451001.MRL | Littelfuse | Littelfuse 0451001.MRL | F501 F511 F521
1 | C178982 | 045106.3MRL | Littelfuse | Littelfuse 045106.3MRL | F711
2 | C13982 | 0451003.MRL | Littelfuse | Littelfuse 0451003.MRL | F721 F904
1 | C19727305 | XF-508P-B-B | XFCN | XFCN XF-508P-B-B | F902
1 | C37208 | 2.54-1x6P | BOOMELE | BOOMELE 2.54-1x6P | J201
1 | C144395 | B4B-XH-A | JST | JST B4B-XH-A | J301
3 | C466970 | DB125-3.5-2P-GN-S | DORABO | DORABO DB125-3.5-2P-GN-S | J302 J521 J601
1 | C91145 | TF-01A | Korean Hroparts Elec | Korean Hroparts Elec TF-01A | J401
2 | C2757925 | DB125-3.5-4P-GN-S | DORABO | DORABO DB125-3.5-4P-GN-S | J501 J511
3 | C8465 | WJ500V-5.08-2P | KANGNEX | KANGNEX WJ500V-5.08-2P | J711 J721 J731
2 | C318884 | TS-1187A-B-A-B | XKB Connection | XKB Connection TS-1187A-B-A-B | SW201 SW202
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

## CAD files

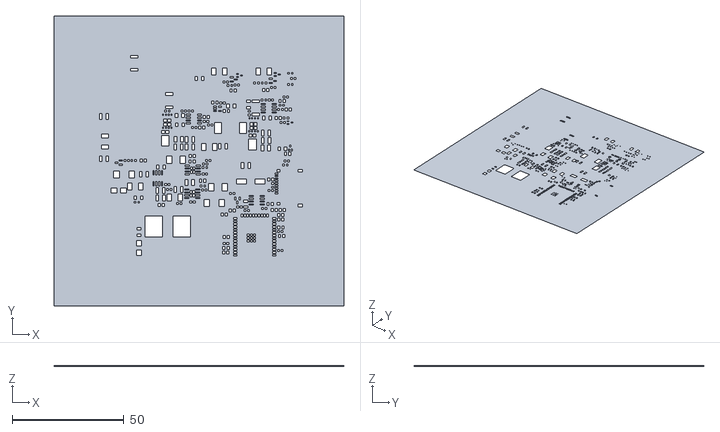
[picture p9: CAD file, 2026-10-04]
hardware/cheap-version/stencil/cheap_full_02_margin15.stl
130.1 x 130.1 x 0.2

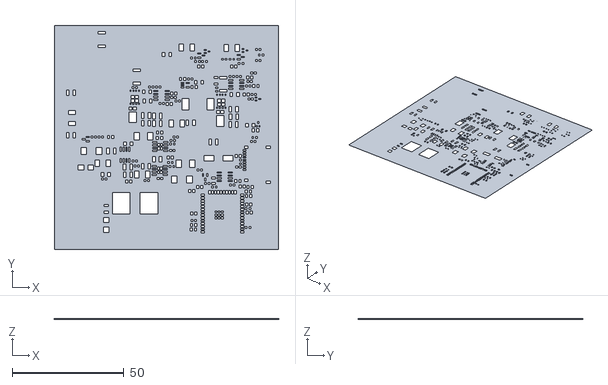
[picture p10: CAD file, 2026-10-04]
hardware/cheap-version/stencil/cheap_full_02.stl
100.1 x 100.1 x 0.2

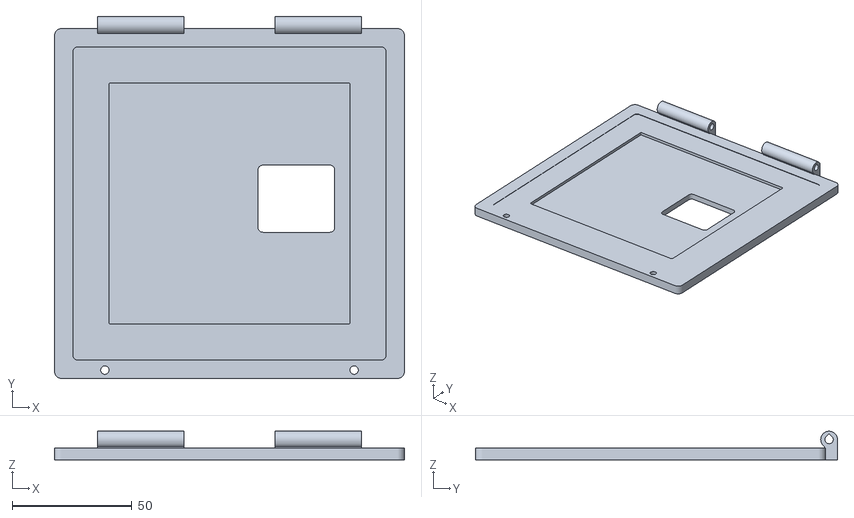
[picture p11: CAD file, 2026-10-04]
hardware/cheap-version/stencil/stencil_jig_base.stl
146.0 x 151.0 x 11.9

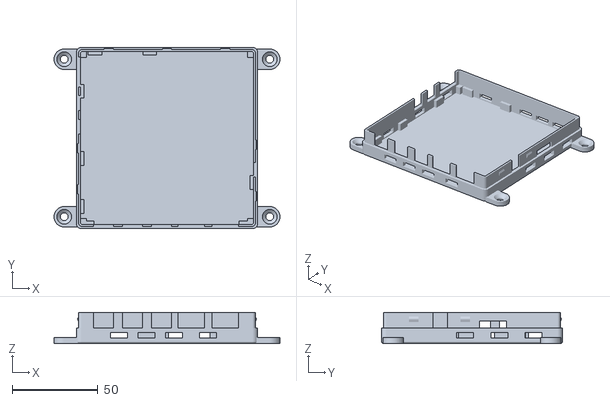
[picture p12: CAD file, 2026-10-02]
hardware/enclosure/GrowBox_base_print.stl
132.0 x 106.0 x 18.2

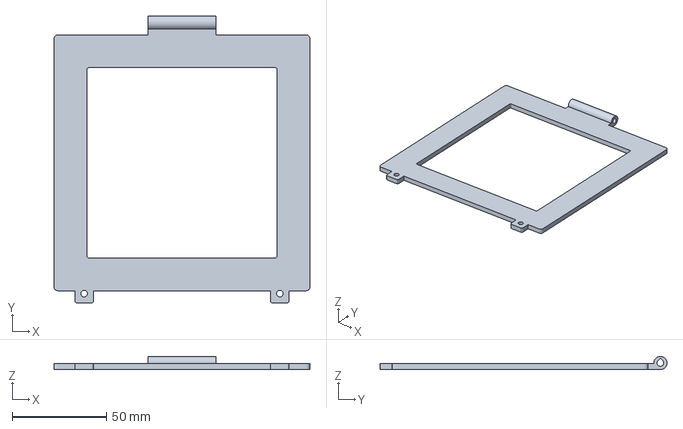
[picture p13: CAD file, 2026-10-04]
hardware/cheap-version/stencil/stencil_jig_frame_geometry.3mf
136.0 x 152.6 x 7.00 mm

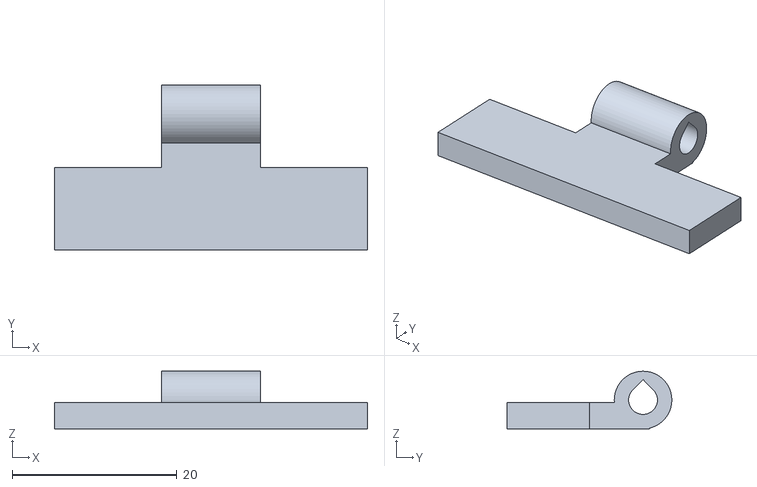
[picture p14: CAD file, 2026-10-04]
hardware/cheap-version/stencil/stencil_jig_hinge_test_frame.stl
38.0 x 20.0 x 7.00

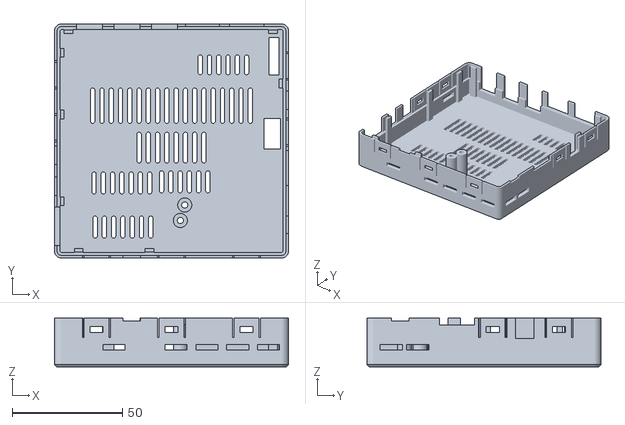
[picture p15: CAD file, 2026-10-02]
hardware/enclosure/GrowBox_lid_print.stl
106.0 x 106.0 x 22.0

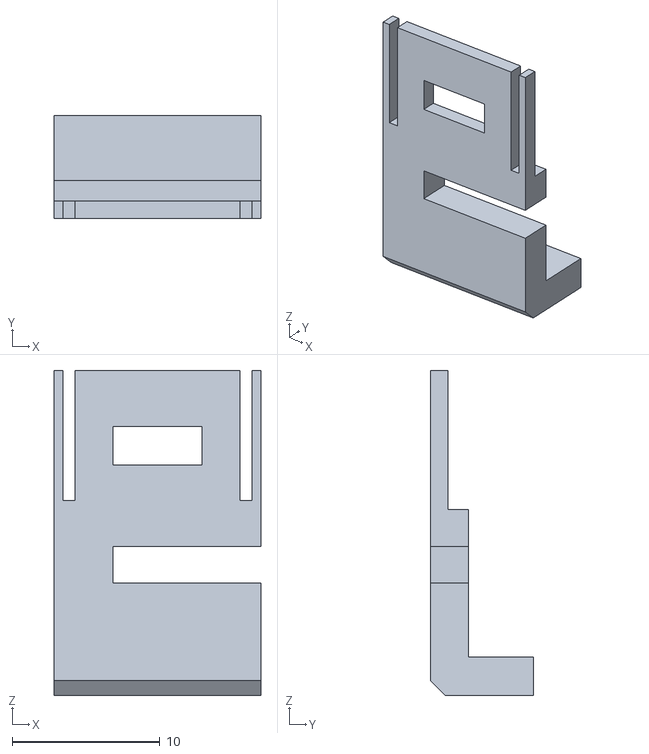
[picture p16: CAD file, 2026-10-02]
hardware/enclosure/GrowBox_lid_coupon_print.stl
14.0 x 7.00 x 22.0

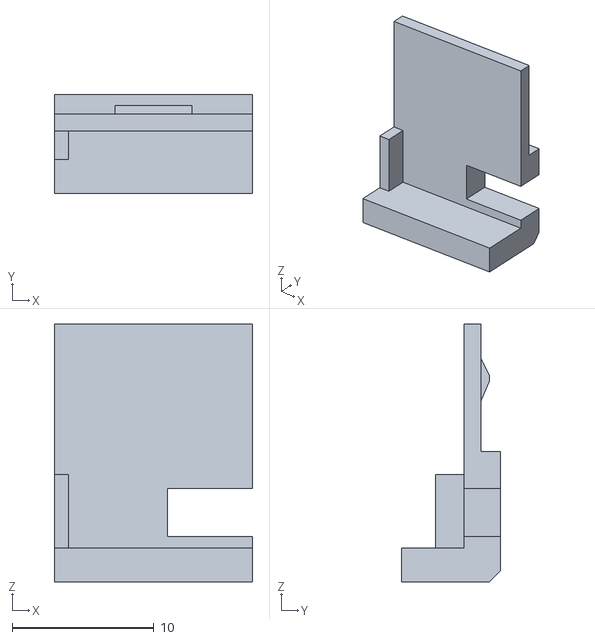
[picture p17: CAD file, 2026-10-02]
hardware/enclosure/GrowBox_base_coupon_print.stl
14.0 x 7.00 x 18.2

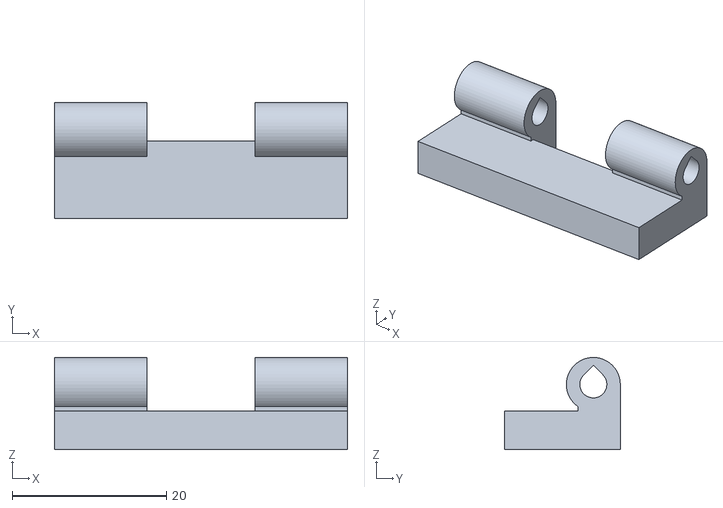
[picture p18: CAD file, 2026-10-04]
hardware/cheap-version/stencil/stencil_jig_hinge_test_base.stl
38.0 x 15.0 x 11.9

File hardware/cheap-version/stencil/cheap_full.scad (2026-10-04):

// Generated by tools/make_stencil.py
// cheap-version full-board stencil
// Board-local coordinates; top paste openings are subtracted from this plate.
plate_w = 100.05000;
plate_h = 100.05000;
plate_t = 0.20000;

difference() {
  cube([plate_w, plate_h, plate_t]);
  translate([0,0,-0.02]) {
    union() {
  linear_extrude(height=0.28000) polygon(points=[[5.24500,71.29500],[6.55500,71.29500],[6.55500,68.75500],[5.24500,68.75500]]);
  linear_extrude(height=0.28000) polygon(points=[[8.19500,71.29500],[9.50500,71.29500],[9.50500,68.75500],[8.19500,68.75500]]);
  linear_extrude(height=0.28000) polygon(points=[[58.69500,57.89500],[60.00500,57.89500],[60.00500,55.35500],[58.69500,55.35500]]);
  linear_extrude(height=0.28000) polygon(points=[[61.64500,57.89500],[62.95500,57.89500],[62.95500,55.35500],[61.64500,55.35500]]);
  linear_extrude(height=0.28000) polygon(points=[[62.57000,84.32000],[63.53000,84.32000],[63.53000,83.53000],[62.57000,83.53000]]);
  linear_extrude(height=0.28000) polygon(points=[[64.22000,84.32000],[65.18000,84.32000],[65.18000,83.53000],[64.22000,83.53000]]);
  linear_extrude(height=0.28000) polygon(points=[[63.37000,28.44500],[64.55500,28.44500],[64.55500,27.20500],[63.37000,27.20500]]);
  linear_extrude(height=0.28000) polygon(points=[[65.19500,28.44500],[66.38000,28.44500],[66.38000,27.20500],[65.19500,27.20500]]);
  linear_extrude(height=0.28000) polygon(points=[[30.64500,38.09500],[31.95500,38.09500],[31.95500,35.55500],[30.64500,35.55500]]);
  linear_extrude(height=0.28000) polygon(points=[[33.59500,38.09500],[34.90500,38.09500],[34.90500,35.55500],[33.59500,35.55500]]);
  linear_extrude(height=0.28000) polygon(points=[[56.94500,67.29500],[60.20500,67.29500],[60.20500,62.45500],[56.94500,62.45500]]);
  linear_extrude(height=0.28000) polygon(points=[[68.04500,67.29500],[71.30500,67.29500],[71.30500,62.45500],[68.04500,62.45500]]);
  linear_extrude(height=0.28000) polygon(points=[[50.47000,39.17000],[51.43000,39.17000],[51.43000,38.38000],[50.47000,38.38000]]);
  linear_extrude(height=0.28000) polygon(points=[[52.12000,39.17000],[53.08000,39.17000],[53.08000,38.38000],[52.12000,38.38000]]);
  linear_extrude(height=0.28000) polygon(points=[[33.05000,40.69500],[33.81000,40.69500],[33.81000,38.90500],[33.05000,38.90500]]);
  linear_extrude(height=0.28000) polygon(points=[[31.78000,40.69500],[32.54000,40.69500],[32.54000,38.90500],[31.78000,38.90500]]);
  linear_extrude(height=0.28000) polygon(points=[[30.51000,40.69500],[31.27000,40.69500],[31.27000,38.90500],[30.51000,38.90500]]);
  linear_extrude(height=0.28000) polygon(points=[[29.24000,40.69500],[30.00000,40.69500],[30.00000,38.90500],[29.24000,38.90500]]);
  linear_extrude(height=0.28000) polygon(points=[[29.24000,45.64500],[30.00000,45.64500],[30.00000,43.85500],[29.24000,43.85500]]);
  linear_extrude(height=0.28000) polygon(points=[[30.51000,45.64500],[31.27000,45.64500],[31.27000,43.85500],[30.51000,43.85500]]);
  linear_extrude(height=0.28000) polygon(points=[[31.78000,45.64500],[32.54000,45.64500],[32.54000,43.85500],[31.78000,43.85500]]);
  linear_extrude(height=0.28000) polygon(points=[[33.05000,45.64500],[33.81000,45.64500],[33.81000,43.85500],[33.05000,43.85500]]);
  linear_extrude(height=0.28000) polygon(points=[[60.67000,16.59500],[61.85500,16.59500],[61.85500,15.35500],[60.67000,15.35500]]);
  linear_extrude(height=0.28000) polygon(points=[[62.49500,16.59500],[63.68000,16.59500],[63.68000,15.35500],[62.49500,15.35500]]);
  linear_extrude(height=0.28000) polygon(points=[[82.42000,37.17000],[83.48000,37.17000],[83.48000,36.38000],[82.42000,36.38000]]);
  linear_extrude(height=0.28000) polygon(points=[[80.87000,37.17000],[81.93000,37.17000],[81.93000,36.38000],[80.87000,36.38000]]);
  linear_extrude(height=0.28000) polygon(points=[[68.89500,49.34500],[70.20500,49.34500],[70.20500,46.80500],[68.89500,46.80500]]);
  linear_extrude(height=0.28000) polygon(points=[[71.84500,49.34500],[73.15500,49.34500],[73.15500,46.80500],[71.84500,46.80500]]);
  linear_extrude(height=0.28000) polygon(points=[[25.74500,25.34500],[33.70500,25.34500],[33.70500,15.90500],[25.74500,15.90500]]);
  linear_extrude(height=0.28000) polygon(points=[[38.24500,25.34500],[46.20500,25.34500],[46.20500,15.90500],[38.24500,15.90500]]);
  linear_extrude(height=0.28000) polygon(points=[[34.97000,74.69500],[38.48000,74.69500],[38.48000,73.63000],[34.97000,73.63000]]);
  linear_extrude(height=0.28000) polygon(points=[[34.97000,80.62000],[38.48000,80.62000],[38.48000,79.55500],[34.97000,79.55500]]);
  linear_extrude(height=0.28000) polygon(points=[[51.47000,49.07000],[52.53000,49.07000],[52.53000,48.28000],[51.47000,48.28000]]);
  linear_extrude(height=0.28000) polygon(points=[[53.02000,49.07000],[54.08000,49.07000],[54.08000,48.28000],[53.02000,48.28000]]);
  linear_extrude(height=0.28000) polygon(points=[[65.67000,84.42000],[66.63000,84.42000],[66.63000,83.63000],[65.67000,83.63000]]);
  linear_extrude(height=0.28000) polygon(points=[[67.32000,84.42000],[68.28000,84.42000],[68.28000,83.63000],[67.32000,83.63000]]);
  linear_extrude(height=0.28000) polygon(points=[[85.27000,20.79500],[86.45500,20.79500],[86.45500,19.55500],[85.27000,19.55500]]);
  linear_extrude(height=0.28000) polygon(points=[[87.09500,20.79500],[88.28000,20.79500],[88.28000,19.55500],[87.09500,19.55500]]);
  linear_extrude(height=0.28000) polygon(points=[[60.59500,11.67000],[61.75500,11.67000],[61.75500,10.38000],[60.59500,10.38000]]);
  linear_extrude(height=0.28000) polygon(points=[[62.49500,11.67000],[63.65500,11.67000],[63.65500,10.38000],[62.49500,10.38000]]);
  linear_extrude(height=0.28000) polygon(points=[[66.74500,41.99500],[71.30500,41.99500],[71.30500,39.65500],[66.74500,39.65500]]);
  linear_extrude(height=0.28000) polygon(points=[[75.14500,41.99500],[79.70500,41.99500],[79.70500,39.65500],[75.14500,39.65500]]);
  linear_extrude(height=0.28000) polygon(points=[[77.92000,85.37000],[78.88000,85.37000],[78.88000,84.58000],[77.92000,84.58000]]);
  linear_extrude(height=0.28000) polygon(points=[[79.57000,85.37000],[80.53000,85.37000],[80.53000,84.58000],[79.57000,84.58000]]);
  linear_extrude(height=0.28000) polygon(points=[[53.72000,66.62000],[54.78000,66.62000],[54.78000,65.83000],[53.72000,65.83000]]);
  linear_extrude(height=0.28000) polygon(points=[[55.27000,66.62000],[56.33000,66.62000],[56.33000,65.83000],[55.27000,65.83000]]);
  linear_extrude(height=0.28000) polygon(points=[[74.52000,85.37000],[75.48000,85.37000],[75.48000,84.58000],[74.52000,84.58000]]);
  linear_extrude(height=0.28000) polygon(points=[[76.17000,85.37000],[77.13000,85.37000],[77.13000,84.58000],[76.17000,84.58000]]);
  linear_extrude(height=0.28000) polygon(points=[[21.02000,50.62000],[21.98000,50.62000],[21.98000,49.83000],[21.02000,49.83000]]);
  linear_extrude(height=0.28000) polygon(points=[[19.37000,50.62000],[20.33000,50.62000],[20.33000,49.83000],[19.37000,49.83000]]);
  linear_extrude(height=0.28000) polygon(points=[[49.77000,65.64500],[50.95500,65.64500],[50.95500,64.40500],[49.77000,64.40500]]);
  linear_extrude(height=0.28000) polygon(points=[[51.59500,65.64500],[52.78000,65.64500],[52.78000,64.40500],[51.59500,64.40500]]);
  linear_extrude(height=0.28000) polygon(points=[[82.32000,28.69500],[83.50500,28.69500],[83.50500,27.45500],[82.32000,27.45500]]);
  linear_extrude(height=0.28000) polygon(points=[[84.14500,28.69500],[85.33000,28.69500],[85.33000,27.45500],[84.14500,27.45500]]);
  linear_extrude(height=0.28000) polygon(points=[[39.92000,31.27000],[40.98000,31.27000],[40.98000,30.48000],[39.92000,30.48000]]);
  linear_extrude(height=0.28000) polygon(points=[[41.47000,31.27000],[42.53000,31.27000],[42.53000,30.48000],[41.47000,30.48000]]);
  linear_extrude(height=0.28000) polygon(points=[[39.39500,67.09500],[40.70500,67.09500],[40.70500,65.45500],[39.39500,65.45500]]);
  linear_extrude(height=0.28000) polygon(points=[[42.34500,67.09500],[43.65500,67.09500],[43.65500,65.45500],[42.34500,65.45500]]);
  linear_extrude(height=0.28000) polygon(points=[[52.14500,32.79500],[54.80500,32.79500],[54.80500,29.65500],[52.14500,29.65500]]);
  linear_extrude(height=0.28000) polygon(points=[[58.94500,32.79500],[61.60500,32.79500],[61.60500,29.65500],[58.94500,29.65500]]);
  linear_extrude(height=0.28000) polygon(points=[[46.62000,65.52000],[47.58000,65.52000],[47.58000,64.73000],[46.62000,64.73000]]);
  linear_extrude(height=0.28000) polygon(points=[[48.27000,65.52000],[49.23000,65.52000],[49.23000,64.73000],[48.27000,64.73000]]);
  linear_extrude(height=0.28000) polygon(points=[[31.62000,30.89500],[32.80500,30.89500],[32.80500,29.65500],[31.62000,29.65500]]);
  linear_extrude(height=0.28000) polygon(points=[[33.44500,30.89500],[34.63000,30.89500],[34.63000,29.65500],[33.44500,29.65500]]);
  linear_extrude(height=0.28000) polygon(points=[[6.17000,57.22000],[9.48000,57.22000],[9.48000,55.42000],[6.17000,55.42000]]);
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

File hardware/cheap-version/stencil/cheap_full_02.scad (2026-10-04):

// Generated by tools/make_stencil.py
// cheap-version full-board stencil
// Board-local coordinates; top paste openings are subtracted from this plate.
plate_w = 100.05000;
plate_h = 100.05000;
plate_t = 0.20000;

difference() {
  cube([plate_w, plate_h, plate_t]);
  translate([0,0,-0.02]) {
    union() {
  linear_extrude(height=0.28000) polygon(points=[[5.29500,71.34500],[6.50500,71.34500],[6.50500,68.70500],[5.29500,68.70500]]);
  linear_extrude(height=0.28000) polygon(points=[[8.24500,71.34500],[9.45500,71.34500],[9.45500,68.70500],[8.24500,68.70500]]);
  linear_extrude(height=0.28000) polygon(points=[[58.74500,57.94500],[59.95500,57.94500],[59.95500,55.30500],[58.74500,55.30500]]);
  linear_extrude(height=0.28000) polygon(points=[[61.69500,57.94500],[62.90500,57.94500],[62.90500,55.30500],[61.69500,55.30500]]);
  linear_extrude(height=0.28000) polygon(points=[[62.62000,84.37000],[63.48000,84.37000],[63.48000,83.48000],[62.62000,83.48000]]);
  linear_extrude(height=0.28000) polygon(points=[[64.27000,84.37000],[65.13000,84.37000],[65.13000,83.48000],[64.27000,83.48000]]);
  linear_extrude(height=0.28000) polygon(points=[[63.42000,28.49500],[64.50500,28.49500],[64.50500,27.15500],[63.42000,27.15500]]);
  linear_extrude(height=0.28000) polygon(points=[[65.24500,28.49500],[66.33000,28.49500],[66.33000,27.15500],[65.24500,27.15500]]);
  linear_extrude(height=0.28000) polygon(points=[[30.69500,38.14500],[31.90500,38.14500],[31.90500,35.50500],[30.69500,35.50500]]);
  linear_extrude(height=0.28000) polygon(points=[[33.64500,38.14500],[34.85500,38.14500],[34.85500,35.50500],[33.64500,35.50500]]);
  linear_extrude(height=0.28000) polygon(points=[[56.99500,67.34500],[60.15500,67.34500],[60.15500,62.40500],[56.99500,62.40500]]);
  linear_extrude(height=0.28000) polygon(points=[[68.09500,67.34500],[71.25500,67.34500],[71.25500,62.40500],[68.09500,62.40500]]);
  linear_extrude(height=0.28000) polygon(points=[[50.52000,39.22000],[51.38000,39.22000],[51.38000,38.33000],[50.52000,38.33000]]);
  linear_extrude(height=0.28000) polygon(points=[[52.17000,39.22000],[53.03000,39.22000],[53.03000,38.33000],[52.17000,38.33000]]);
  linear_extrude(height=0.28000) polygon(points=[[33.10000,40.74500],[33.76000,40.74500],[33.76000,38.85500],[33.10000,38.85500]]);
  linear_extrude(height=0.28000) polygon(points=[[31.83000,40.74500],[32.49000,40.74500],[32.49000,38.85500],[31.83000,38.85500]]);
  linear_extrude(height=0.28000) polygon(points=[[30.56000,40.74500],[31.22000,40.74500],[31.22000,38.85500],[30.56000,38.85500]]);
  linear_extrude(height=0.28000) polygon(points=[[29.29000,40.74500],[29.95000,40.74500],[29.95000,38.85500],[29.29000,38.85500]]);
  linear_extrude(height=0.28000) polygon(points=[[29.29000,45.69500],[29.95000,45.69500],[29.95000,43.80500],[29.29000,43.80500]]);
  linear_extrude(height=0.28000) polygon(points=[[30.56000,45.69500],[31.22000,45.69500],[31.22000,43.80500],[30.56000,43.80500]]);
  linear_extrude(height=0.28000) polygon(points=[[31.83000,45.69500],[32.49000,45.69500],[32.49000,43.80500],[31.83000,43.80500]]);
  linear_extrude(height=0.28000) polygon(points=[[33.10000,45.69500],[33.76000,45.69500],[33.76000,43.80500],[33.10000,43.80500]]);
  linear_extrude(height=0.28000) polygon(points=[[60.72000,16.64500],[61.80500,16.64500],[61.80500,15.30500],[60.72000,15.30500]]);
  linear_extrude(height=0.28000) polygon(points=[[62.54500,16.64500],[63.63000,16.64500],[63.63000,15.30500],[62.54500,15.30500]]);
  linear_extrude(height=0.28000) polygon(points=[[82.47000,37.22000],[83.43000,37.22000],[83.43000,36.33000],[82.47000,36.33000]]);
  linear_extrude(height=0.28000) polygon(points=[[80.92000,37.22000],[81.88000,37.22000],[81.88000,36.33000],[80.92000,36.33000]]);
  linear_extrude(height=0.28000) polygon(points=[[68.94500,49.39500],[70.15500,49.39500],[70.15500,46.75500],[68.94500,46.75500]]);
  linear_extrude(height=0.28000) polygon(points=[[71.89500,49.39500],[73.10500,49.39500],[73.10500,46.75500],[71.89500,46.75500]]);
  linear_extrude(height=0.28000) polygon(points=[[25.79500,25.39500],[33.65500,25.39500],[33.65500,15.85500],[25.79500,15.85500]]);
  linear_extrude(height=0.28000) polygon(points=[[38.29500,25.39500],[46.15500,25.39500],[46.15500,15.85500],[38.29500,15.85500]]);
  linear_extrude(height=0.28000) polygon(points=[[35.02000,74.74500],[38.43000,74.74500],[38.43000,73.58000],[35.02000,73.58000]]);
  linear_extrude(height=0.28000) polygon(points=[[35.02000,80.67000],[38.43000,80.67000],[38.43000,79.50500],[35.02000,79.50500]]);
  linear_extrude(height=0.28000) polygon(points=[[51.52000,49.12000],[52.48000,49.12000],[52.48000,48.23000],[51.52000,48.23000]]);
  linear_extrude(height=0.28000) polygon(points=[[53.07000,49.12000],[54.03000,49.12000],[54.03000,48.23000],[53.07000,48.23000]]);
  linear_extrude(height=0.28000) polygon(points=[[65.72000,84.47000],[66.58000,84.47000],[66.58000,83.58000],[65.72000,83.58000]]);
  linear_extrude(height=0.28000) polygon(points=[[67.37000,84.47000],[68.23000,84.47000],[68.23000,83.58000],[67.37000,83.58000]]);
  linear_extrude(height=0.28000) polygon(points=[[85.32000,20.84500],[86.40500,20.84500],[86.40500,19.50500],[85.32000,19.50500]]);
  linear_extrude(height=0.28000) polygon(points=[[87.14500,20.84500],[88.23000,20.84500],[88.23000,19.50500],[87.14500,19.50500]]);
  linear_extrude(height=0.28000) polygon(points=[[60.64500,11.72000],[61.70500,11.72000],[61.70500,10.33000],[60.64500,10.33000]]);
  linear_extrude(height=0.28000) polygon(points=[[62.54500,11.72000],[63.60500,11.72000],[63.60500,10.33000],[62.54500,10.33000]]);
  linear_extrude(height=0.28000) polygon(points=[[66.79500,42.04500],[71.25500,42.04500],[71.25500,39.60500],[66.79500,39.60500]]);
  linear_extrude(height=0.28000) polygon(points=[[75.19500,42.04500],[79.65500,42.04500],[79.65500,39.60500],[75.19500,39.60500]]);
  linear_extrude(height=0.28000) polygon(points=[[77.97000,85.42000],[78.83000,85.42000],[78.83000,84.53000],[77.97000,84.53000]]);
  linear_extrude(height=0.28000) polygon(points=[[79.62000,85.42000],[80.48000,85.42000],[80.48000,84.53000],[79.62000,84.53000]]);
  linear_extrude(height=0.28000) polygon(points=[[53.77000,66.67000],[54.73000,66.67000],[54.73000,65.78000],[53.77000,65.78000]]);
  linear_extrude(height=0.28000) polygon(points=[[55.32000,66.67000],[56.28000,66.67000],[56.28000,65.78000],[55.32000,65.78000]]);
  linear_extrude(height=0.28000) polygon(points=[[74.57000,85.42000],[75.43000,85.42000],[75.43000,84.53000],[74.57000,84.53000]]);
  linear_extrude(height=0.28000) polygon(points=[[76.22000,85.42000],[77.08000,85.42000],[77.08000,84.53000],[76.22000,84.53000]]);
  linear_extrude(height=0.28000) polygon(points=[[21.07000,50.67000],[21.93000,50.67000],[21.93000,49.78000],[21.07000,49.78000]]);
  linear_extrude(height=0.28000) polygon(points=[[19.42000,50.67000],[20.28000,50.67000],[20.28000,49.78000],[19.42000,49.78000]]);
  linear_extrude(height=0.28000) polygon(points=[[49.82000,65.69500],[50.90500,65.69500],[50.90500,64.35500],[49.82000,64.35500]]);
  linear_extrude(height=0.28000) polygon(points=[[51.64500,65.69500],[52.73000,65.69500],[52.73000,64.35500],[51.64500,64.35500]]);
  linear_extrude(height=0.28000) polygon(points=[[82.37000,28.74500],[83.45500,28.74500],[83.45500,27.40500],[82.37000,27.40500]]);
  linear_extrude(height=0.28000) polygon(points=[[84.19500,28.74500],[85.28000,28.74500],[85.28000,27.40500],[84.19500,27.40500]]);
  linear_extrude(height=0.28000) polygon(points=[[39.97000,31.32000],[40.93000,31.32000],[40.93000,30.43000],[39.97000,30.43000]]);
  linear_extrude(height=0.28000) polygon(points=[[41.52000,31.32000],[42.48000,31.32000],[42.48000,30.43000],[41.52000,30.43000]]);
  linear_extrude(height=0.28000) polygon(points=[[39.44500,67.14500],[40.65500,67.14500],[40.65500,65.40500],[39.44500,65.40500]]);
  linear_extrude(height=0.28000) polygon(points=[[42.39500,67.14500],[43.60500,67.14500],[43.60500,65.40500],[42.39500,65.40500]]);
  linear_extrude(height=0.28000) polygon(points=[[52.19500,32.84500],[54.75500,32.84500],[54.75500,29.60500],[52.19500,29.60500]]);
  linear_extrude(height=0.28000) polygon(points=[[58.99500,32.84500],[61.55500,32.84500],[61.55500,29.60500],[58.99500,29.60500]]);
  linear_extrude(height=0.28000) polygon(points=[[46.67000,65.57000],[47.53000,65.57000],[47.53000,64.68000],[46.67000,64.68000]]);
  linear_extrude(height=0.28000) polygon(points=[[48.32000,65.57000],[49.18000,65.57000],[49.18000,64.68000],[48.32000,64.68000]]);
  linear_extrude(height=0.28000) polygon(points=[[31.67000,30.94500],[32.75500,30.94500],[32.75500,29.60500],[31.67000,29.60500]]);
  linear_extrude(height=0.28000) polygon(points=[[33.49500,30.94500],[34.58000,30.94500],[34.58000,29.60500],[33.49500,29.60500]]);
  linear_extrude(height=0.28000) polygon(points=[[6.22000,57.27000],[9.43000,57.27000],[9.43000,55.37000],[6.22000,55.37000]]);
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

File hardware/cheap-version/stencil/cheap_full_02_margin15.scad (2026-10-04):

// Generated by tools/make_stencil.py
// cheap-version full-board stencil
// Board-local coordinates; top paste openings are subtracted from this plate.
plate_w = 130.05000;
plate_h = 130.05000;
plate_t = 0.20000;

difference() {
  cube([plate_w, plate_h, plate_t]);
  translate([0,0,-0.02]) {
    union() {
  linear_extrude(height=0.28000) polygon(points=[[20.29500,86.34500],[21.50500,86.34500],[21.50500,83.70500],[20.29500,83.70500]]);
  linear_extrude(height=0.28000) polygon(points=[[23.24500,86.34500],[24.45500,86.34500],[24.45500,83.70500],[23.24500,83.70500]]);
  linear_extrude(height=0.28000) polygon(points=[[73.74500,72.94500],[74.95500,72.94500],[74.95500,70.30500],[73.74500,70.30500]]);
  linear_extrude(height=0.28000) polygon(points=[[76.69500,72.94500],[77.90500,72.94500],[77.90500,70.30500],[76.69500,70.30500]]);
  linear_extrude(height=0.28000) polygon(points=[[77.62000,99.37000],[78.48000,99.37000],[78.48000,98.48000],[77.62000,98.48000]]);
  linear_extrude(height=0.28000) polygon(points=[[79.27000,99.37000],[80.13000,99.37000],[80.13000,98.48000],[79.27000,98.48000]]);
  linear_extrude(height=0.28000) polygon(points=[[78.42000,43.49500],[79.50500,43.49500],[79.50500,42.15500],[78.42000,42.15500]]);
  linear_extrude(height=0.28000) polygon(points=[[80.24500,43.49500],[81.33000,43.49500],[81.33000,42.15500],[80.24500,42.15500]]);
  linear_extrude(height=0.28000) polygon(points=[[45.69500,53.14500],[46.90500,53.14500],[46.90500,50.50500],[45.69500,50.50500]]);
  linear_extrude(height=0.28000) polygon(points=[[48.64500,53.14500],[49.85500,53.14500],[49.85500,50.50500],[48.64500,50.50500]]);
  linear_extrude(height=0.28000) polygon(points=[[71.99500,82.34500],[75.15500,82.34500],[75.15500,77.40500],[71.99500,77.40500]]);
  linear_extrude(height=0.28000) polygon(points=[[83.09500,82.34500],[86.25500,82.34500],[86.25500,77.40500],[83.09500,77.40500]]);
  linear_extrude(height=0.28000) polygon(points=[[65.52000,54.22000],[66.38000,54.22000],[66.38000,53.33000],[65.52000,53.33000]]);
  linear_extrude(height=0.28000) polygon(points=[[67.17000,54.22000],[68.03000,54.22000],[68.03000,53.33000],[67.17000,53.33000]]);
  linear_extrude(height=0.28000) polygon(points=[[48.10000,55.74500],[48.76000,55.74500],[48.76000,53.85500],[48.10000,53.85500]]);
  linear_extrude(height=0.28000) polygon(points=[[46.83000,55.74500],[47.49000,55.74500],[47.49000,53.85500],[46.83000,53.85500]]);
  linear_extrude(height=0.28000) polygon(points=[[45.56000,55.74500],[46.22000,55.74500],[46.22000,53.85500],[45.56000,53.85500]]);
  linear_extrude(height=0.28000) polygon(points=[[44.29000,55.74500],[44.95000,55.74500],[44.95000,53.85500],[44.29000,53.85500]]);
  linear_extrude(height=0.28000) polygon(points=[[44.29000,60.69500],[44.95000,60.69500],[44.95000,58.80500],[44.29000,58.80500]]);
  linear_extrude(height=0.28000) polygon(points=[[45.56000,60.69500],[46.22000,60.69500],[46.22000,58.80500],[45.56000,58.80500]]);
  linear_extrude(height=0.28000) polygon(points=[[46.83000,60.69500],[47.49000,60.69500],[47.49000,58.80500],[46.83000,58.80500]]);
  linear_extrude(height=0.28000) polygon(points=[[48.10000,60.69500],[48.76000,60.69500],[48.76000,58.80500],[48.10000,58.80500]]);
  linear_extrude(height=0.28000) polygon(points=[[75.72000,31.64500],[76.80500,31.64500],[76.80500,30.30500],[75.72000,30.30500]]);
  linear_extrude(height=0.28000) polygon(points=[[77.54500,31.64500],[78.63000,31.64500],[78.63000,30.30500],[77.54500,30.30500]]);
  linear_extrude(height=0.28000) polygon(points=[[97.47000,52.22000],[98.43000,52.22000],[98.43000,51.33000],[97.47000,51.33000]]);
  linear_extrude(height=0.28000) polygon(points=[[95.92000,52.22000],[96.88000,52.22000],[96.88000,51.33000],[95.92000,51.33000]]);
  linear_extrude(height=0.28000) polygon(points=[[83.94500,64.39500],[85.15500,64.39500],[85.15500,61.75500],[83.94500,61.75500]]);
  linear_extrude(height=0.28000) polygon(points=[[86.89500,64.39500],[88.10500,64.39500],[88.10500,61.75500],[86.89500,61.75500]]);
  linear_extrude(height=0.28000) polygon(points=[[40.79500,40.39500],[48.65500,40.39500],[48.65500,30.85500],[40.79500,30.85500]]);
  linear_extrude(height=0.28000) polygon(points=[[53.29500,40.39500],[61.15500,40.39500],[61.15500,30.85500],[53.29500,30.85500]]);
  linear_extrude(height=0.28000) polygon(points=[[50.02000,89.74500],[53.43000,89.74500],[53.43000,88.58000],[50.02000,88.58000]]);
  linear_extrude(height=0.28000) polygon(points=[[50.02000,95.67000],[53.43000,95.67000],[53.43000,94.50500],[50.02000,94.50500]]);
  linear_extrude(height=0.28000) polygon(points=[[66.52000,64.12000],[67.48000,64.12000],[67.48000,63.23000],[66.52000,63.23000]]);
  linear_extrude(height=0.28000) polygon(points=[[68.07000,64.12000],[69.03000,64.12000],[69.03000,63.23000],[68.07000,63.23000]]);
  linear_extrude(height=0.28000) polygon(points=[[80.72000,99.47000],[81.58000,99.47000],[81.58000,98.58000],[80.72000,98.58000]]);
  linear_extrude(height=0.28000) polygon(points=[[82.37000,99.47000],[83.23000,99.47000],[83.23000,98.58000],[82.37000,98.58000]]);
  linear_extrude(height=0.28000) polygon(points=[[100.32000,35.84500],[101.40500,35.84500],[101.40500,34.50500],[100.32000,34.50500]]);
  linear_extrude(height=0.28000) polygon(points=[[102.14500,35.84500],[103.23000,35.84500],[103.23000,34.50500],[102.14500,34.50500]]);
  linear_extrude(height=0.28000) polygon(points=[[75.64500,26.72000],[76.70500,26.72000],[76.70500,25.33000],[75.64500,25.33000]]);
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

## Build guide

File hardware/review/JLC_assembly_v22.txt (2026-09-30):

PCB_V1 v0.22 JLCPCB PCB + assembly estimate, JLC snapshot 2026-09-28 (base); 2026-09-29 (v18/v19); 2026-09-30 (v20-v22 parts)
Fees: https://jlcpcb.com/help/article/pcb-assembly-price (last updated 2026-09-09). EUR at ECB 2026-09-28: 1 EUR = 1.1378 USD.
PCB: https://cart.jlcpcb.com/quote: FR-4, 4 layers, 100x100 mm, 5 pcs, 1.6 mm, 1 oz outer / 0.5 oz inner, green, LeadFree HASL: USD 36.50 for 5 pcs (engineering fee 25.00 + board 6.20 + LeadFree HASL 5.30; HASL with lead 31.20, ENIG 48.90).
Unique parts 66: basic 15, preferred 3, extended 48 (40 placed by machine, 8 through-hole). Joints per board: SMT 410 (pads), through-hole 40. X-ray refs per board: Q601.
Not included: shipping, VAT/duty, coupons, programming/testing. Leftover parts stay in the JLCPCB parts library.

Order totals (5 PCBs made in every case; n boards assembled):
  Economic PCBA, single-sided, 2 assembled: PCB 36.50 + assembly 141.99 + JLC parts 70.72 + separate 0.62 = USD 249.83 = EUR 219.58; USD 124.92 per assembled board
      setup 8.18; stencil 1.53; SMT 820 joints 1.31; through-hole 80 joints 1.31; hand-soldering labour 3.58; extended part loading x40 122.80; X-ray 2 pcs 3.28
  Economic PCBA, single-sided, 5 assembled: PCB 36.50 + assembly 150.85 + JLC parts 148.86 + separate 0.62 = USD 336.83 = EUR 296.03; USD 67.37 per assembled board
      setup 8.18; stencil 1.53; SMT 2050 joints 3.28; through-hole 200 joints 3.28; hand-soldering labour 3.58; extended part loading x40 122.80; X-ray 5 pcs 8.20
  Standard PCBA, double-sided, 2 assembled: PCB 36.50 + assembly 194.93 + JLC parts 70.72 + separate 0.62 = USD 302.77 = EUR 266.10; USD 151.38 per assembled board
      setup 51.12; stencil 16.42; SMT 820 joints 1.31; through-hole 80 joints 1.31; hand-soldering labour 3.58; feeder loading x66 100.98; packing 0.51; fixtures 16.42; X-ray 2 pcs 3.28
  Standard PCBA, double-sided, 5 assembled: PCB 36.50 + assembly 203.80 + JLC parts 148.86 + separate 0.62 = USD 389.77 = EUR 342.57; USD 77.95 per assembled board
      setup 51.12; stencil 16.42; SMT 2050 joints 3.28; through-hole 200 joints 3.28; hand-soldering labour 3.58; feeder loading x66 100.98; packing 0.52; fixtures 16.42; X-ray 5 pcs 8.20

refs                                 LCSC type qty  SMT  THT n=2 pcs     USD n=5 pcs     USD  part
J901                               C98732 E      1    0    4       2    1.20       5    3.00  Amass XT60PW-M
D601,D901                         C515606 E      2    4    0       5    0.51      10    1.03  Vishay SMBJ26CA-E3/52
C901                              C178549 E      1    2    0       2    1.02       5    2.55  Panasonic EEEFK1H221P
C902                               C40708 E      1    2    0       5    0.65       7    0.91  Samsung CL32B105KBHNNNE
F902                            C19727305 E      1    0    4       2    0.55       5    1.37  XFCN XF-508P-B-B
U902                              C190006 E      1   14    0       2    1.61       5    4.04  TI LMR16020PDDAR
D521,D902                          C35722 P      2    4    0       4    1.32      10    3.29  Vishay SS36-E3/57T
C521,C710,C715,C725,C905,C906     C386166 E      6   12    0      14    4.05      32    9.25  Taiyo Yuden UMK325AB7106KMHP
C102..C908 (10)                     C1591 E     10   20    0      30    0.25      60    0.50  Samsung CL10B104KB8NNNC
C909                              C136279 E      1    2    0       2    1.72       5    4.30  Panasonic 25SVPF100M
C101,C910                         C309062 E      2    4    0       6    2.12      12    3.34  Samsung CL32B226KAJNNNE
R904                              C326734 E      1    2    0      20    0.86      20    0.86  Yageo RT0603BRD07150KL
R905                               C95204 E      1    2    0      20    0.65      20    0.65  Yageo RT0603BRD0710KL
R907                               C23203 P      1    2    0      20    0.03      20    0.03  UNI-ROYAL 0603WAF5603T5E
U101                              C191884 E      1    6    0       5    0.86       5    0.86  TI TPS54202DDCR
C104,C105,C401                     C29277 E      3    6    0       6    0.49      15    1.22  Samsung CL21A226MPQNNNE
C201,C602                          C15850 B      2    4    0      20    1.58      20    1.58  Samsung CL21A106KAYNNNE
C203,C302                          C29936 E      2    4    0      20    0.35      20    0.35  Samsung CL10B105KA8NNNC
U201                              C701341 E      1   47    0       2    7.46       5   18.65  Espressif ESP32-WROOM-32E-N4
BT301                            C2979167 E      1    0    2       2    0.79       5    1.97  MYOUNG BS-07-A1BJ001
J201                               C37208 E      1    0    6       2    0.08       5    0.21  BOOMELE 2.54-1x6P
J301                              C144395 E      1    0    4       3    0.18       6    0.37  JST B4B-XH-A(LF)(SN)
J401                               C91145 E      1   13    0       2    0.38       5    0.96  HRO TF-01A (Korean Hroparts Elec)
D301,D302,D501,D511              C5350871 E      4   12    0      10    1.12      22    2.46  TECH PUBLIC TPD2E2U06DCKR-TP
F301                               C70065 E      1    2    0      20    0.61      20    0.61  TECHFUSE nSMD010
SW201,SW202                       C318884 B      2    8    0       9    0.18      15    0.31  XKB TS-1187A-B-A-B
R201..R728 (19)                    C25804 B     19   38    0      48    0.09     105    0.19  UNI-ROYAL 0603WAF1002T5E
R204..R712 (8)                     C21190 B      8   16    0      26    0.07      50    0.13  UNI-ROYAL 0603WAF1001T5E
R301,R302                          C23162 B      2    4    0      20    0.06      20    0.06  UNI-ROYAL 0603WAF4701T5E
R303..R521 (9)                     C23140 B      9   18    0      28    0.07      55    0.14  UNI-ROYAL 0603WAF330JT5E
R101..R723 (7)                     C25803 B      7   14    0      24    0.07      45    0.14  UNI-ROYAL 0603WAF1003T5E
R601,R711,R721                     C22859 B      3    6    0      20    0.06      25    0.08  UNI-ROYAL 0603WAF100JT5E
R703,R906,R908                    C105579 E      3    6    0      20    0.06      25    0.08  Yageo RC0603FR-0747KL
R717,R727                          C25814 E      2    4    0      20    0.05      20    0.05  UNI-ROYAL 0603WAF3163T5E
R722                               C13167 B      1    2    0      20    0.06      20    0.06  UNI-ROYAL 0603WAF2701T5E
Q501,Q511                          C20917 B      2    6    0       8    0.68      14    1.18  AOS AO3400A
Q521                               C37130 E      1    3    0       6    0.81       9    1.21  AOS AO3422
F501,F511,F521                      C3099 E      3    6    0       8    2.01      17    4.26  Littelfuse 0451001.MRL
J302,J521,J601                    C466970 E      3    0    6       6    1.09      15    2.72  DORABO DB125-3.5-2P-GN-S
J501,J511                        C2757925 E      2    0    8       4    1.60      10    3.99  DORABO DB125-3.5-4P-GN-S
Q601                              C145537 E      1    5    0       2    1.54       5    3.86  onsemi NTMFS5C628NLT1G
U601                              C185857 E      1    8    0       2    0.55       5    1.38  TI UCC27524ADR
U700                                C7666 E      1    5    0       6    0.29       9    0.44  TI SN74LVC1G08DBVR
U710,U720                        C3192318 E      2   16    0       4    3.72      10    7.26  Diodes AL8853S-13
L711                             C2041872 E      1    2    0       2    6.04       5   15.09  Bourns SRP1770TA-470M
L721                              C840530 E      1    2    0       2    2.22       5    5.56  Bourns SRP1265A-470M
C711,C721                          C28323 B      2    4    0      20    0.79      20    0.79  Samsung CL21B105KBFNNNE
C712,C713,C722,C723                C14858 B      4    8    0      20    0.17      30    0.26  Samsung CL10C101JB8NNNC
C714,C724                          C64705 E      2    4    0      20    0.36      20    0.36  Samsung CL10B224KB8NNNC
C716..C728 (7)                    C576517 E      7   14    0      14    6.37      35   14.39  Murata GRM32EC72A106KE05L
R715                            C19633795 E      1    2    0       5    0.50       7    0.70  UNI-ROYAL LR123WF270MT4E
R716                            C48533605 E      1    2    0       5    0.36       7    0.50  FOJAN FRM252WFR180TM
R725                            C52015951 E      1    2    0       5    0.25       7    0.35  RVR HIXD25NR047F
R726                            C22464907 E      1    2    0       6    0.16       9    0.24  TA-I RLH12FTCR430
F711                              C178982 E      1    2    0       5    1.22       5    1.22  Littelfuse 045106.3MRL
F721,F904                          C13982 E      2    4    0       6    1.53      12    3.06  Littelfuse 0451003.MRL
J711,J721,J731                      C8465 E      3    0    6       6    0.80      15    2.00  KANGNEX WJ500V-5.08-2P
R102                               C31850 B      1    2    0      20    0.08      20    0.08  UNI-ROYAL 0603WAF2202T5E
U301                                C7440 P      1    8    0       2    1.21       5    3.03  NXP PCF8563T/5,518
Y301                               C32346 B      1    2    0       5    0.86       5    0.86  Epson Q13FC13500004 (FC-135 32.768 kHz, CL 12.5 pF, +/-20 ppm)
C304                                C1647 B      1    2    0      20    0.31      20    0.31  Samsung CL10C180JB8NNNC
D303                               C68970 E      1    3    0      10    0.30      10    0.30  JSCJ BAV170
Q711,Q721                         C485687 E      2    6    0       4    1.73      10    3.84  AOS AOD66923
D711,D721                          C46986 E      2    6    0       5    1.43      10    2.86  Vishay SS5P10-M3/86A
L101                              C167223 E      1    2    0       3    0.27       6    0.54  cjiang FXL0630-100-M
L902                            C53190553 E      1    2    0       2    0.25       5    0.61  PROD Tech PSPMAA0604-220M-ANP

Bought separately (not assembled by JLCPCB):
  Littelfuse 0297010.WXNV (F902 insert): LCSC C151094, order 2 boards 5 pcs USD 0.62, 5 boards 5 pcs USD 0.62
  CR2032 cell (BT301): not priced - no CR2032 cell found at LCSC on the snapshot date; buy locally

JLCPCB availability below the charged quantity (orderable stock at the snapshot date):
  2 boards: J901 C98732 Amass XT60PW-M: orderable -1553, needs 2
  5 boards: J901 C98732 Amass XT60PW-M: orderable -1553, needs 5

X-ray assumption: leadless power package (SO-8FL); the v0.20 DPAK and TO-277A tabs are visible at the package edge; ESP32 module bottom pad may add one more per board.
Extended loading is charged for the 40 machine-placed extended types only; if JLCPCB also charges the 8 through-hole extended types, add USD 24.56 (Economic).

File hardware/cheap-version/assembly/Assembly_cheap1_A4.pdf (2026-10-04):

# GrowBox cheap-1 — схема установки SMD-деталей (вид сверху)

142 SMD-деталей, из них 141 сверху и C911 снизу. Позиции — по таблице на следующей странице. Зелёные детали — без полярности, оранжевые — с полярностью; красный кружок — вывод, к которому должна встать метка на детали. Номинал рядом с позицией — там, где хватило места, полный список — в таблице. Нижняя сторона (плата перевёрнута, зеркально): C911

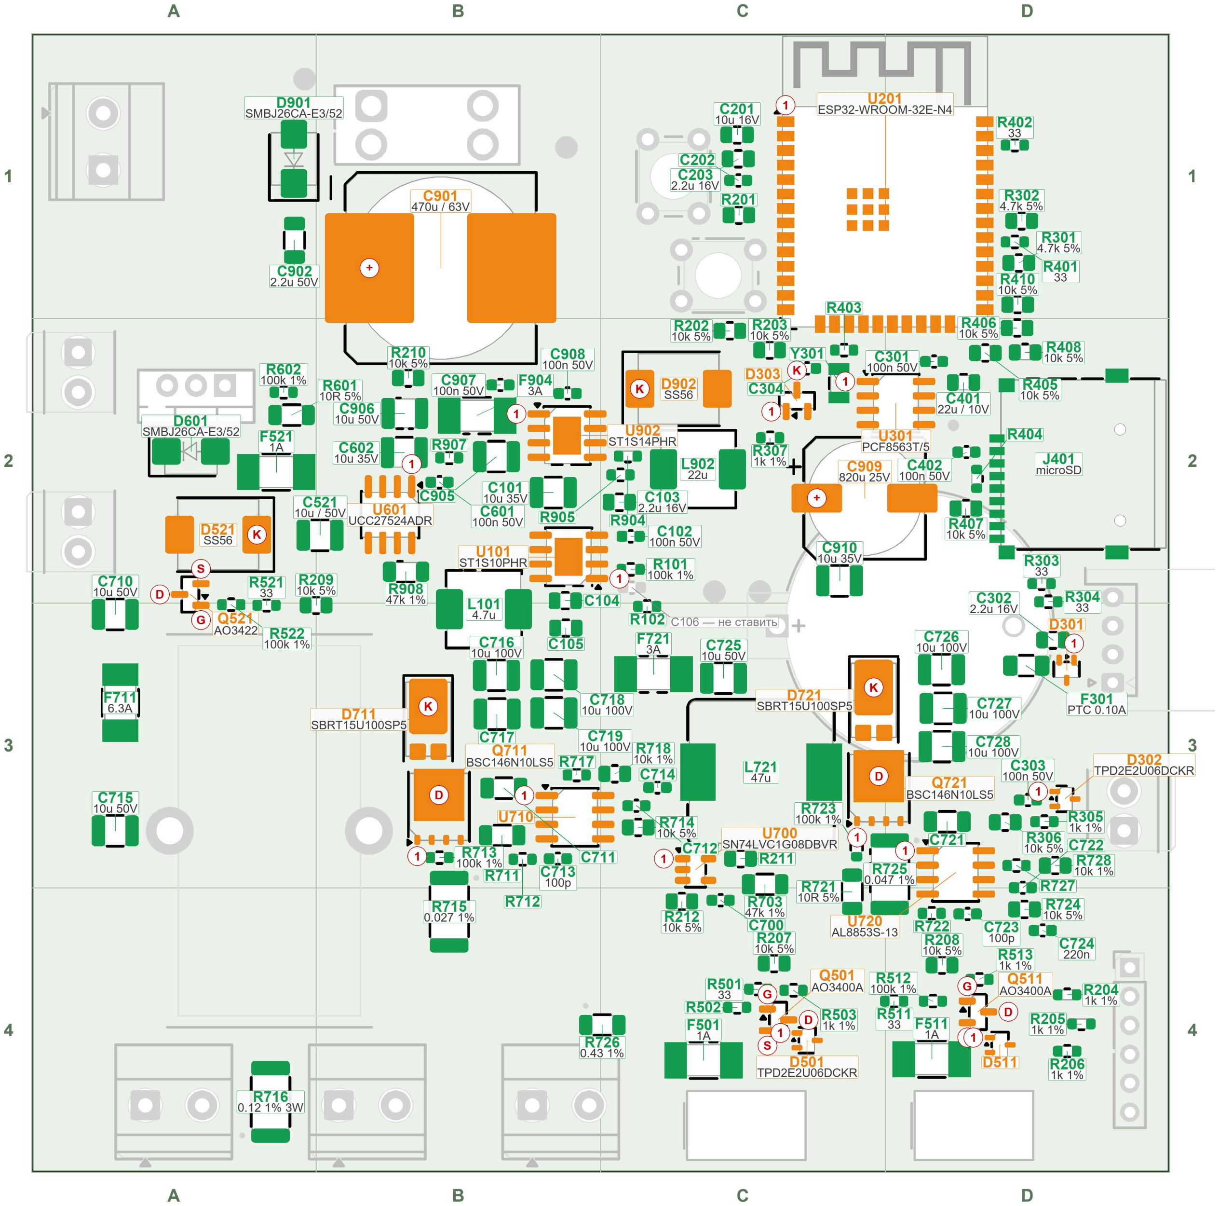
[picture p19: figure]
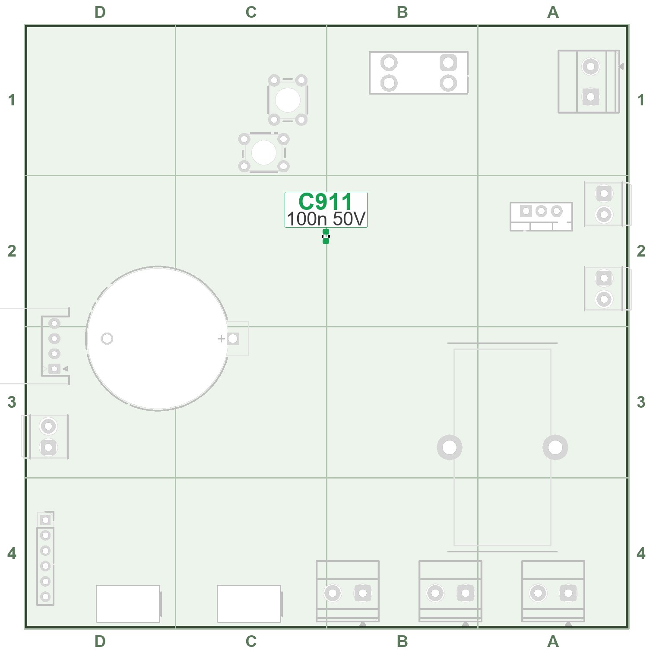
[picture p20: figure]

### Метки полярности на схеме

K катод диода — полоса на корпусе
+ / − | плюс / минус
1 вывод 1: точка, скос или метка на корпусе | микросхемы
G S D | затвор, исток, сток

Серые детали — не из этой схемы (контекст). Сетка A– D, 1–4 — зоны 25 × 25 мм, как в столбце «Зоны» таблицы.

### Цвет детали

без полярности: резисторы, керамика, индуктивности, предохранители, кварц, SMBJ (D601, D901), microSD
с полярностью или выводом 1: диоды, электролиты, транзисторы, микросхемы, ESP32 — по красной метке

### Порядок пайки (колонка «Шаг»)

1 — C911 снизу; 2 — микросхемы; 3 — транзисторы и диоды; 4 — 0603; 5 — 0805; 6 — 1206, 1210, 2512, F301; 7 — индуктивности, предохранители Littelfuse, кварц, C901 и C909; 8 — ESP32 и microSD.

# SMD-детали — позиции и MPN (142 шт., 56 строк)

Позиции | Шт. | Номинал | Корпус | MPN | Полярность / ориентация | Шаг | Зоны
C101 C602 C910 | 3 | 10u 35V | 1210 | CL32A106KLULNNE | — | 6 | B2 C2
C102 C202 C301 C303 C402 C601 C700 C907 C908 C911 (снизу) | 10 | 100n 50V | 0603 | CL10B104KB8NNNC | — | 1, 4 | B2 C1 C2 C4 D2 D3
C103 C203 C302 | 3 | 2.2u 16V | 0805 | CL21A225KOFNNNE | — | 5 | C1 C2 D3
C104 C105 C401 | 3 | 22u / 10V | 0805 | CL21A226KPCLRNC | — | 5 | B2 B3 D2
C201 | 1 | 10u 16V | 0805 | CL21A106KAYNNNE | — | 5 | C1
C304 | 1 | 18p 50V | 0603 | CL10C180JB8NNNC | — | 4 | C2
C521 | 1 | 10u / 50V | 1210 | CL32B106KBJNNNE | — | 6 | B2
C710 C715 C725 C905 C906 | 5 | 10u 50V | 1210 | CL32B106KBJNNNE | — | 6 | A3 B2 C3
C711 C721 C902 | 3 | 2.2u 50V | 1206 | 12065C225KATM-HW | — | 6 | A1 B3 D3
C712 C713 C722 C723 | 4 | 100p | 0603 | CL10C101JB8NNNC | — | 4 | B3 C3 D4
C714 C724 | 2 | 220n | 0603 | CL10B224KB8NNNC | — | 4 | C3 D4
C716 C717 C718 C719 C726 C727 C728 | 7 | 10u 100V | 1210 | GRM32EC72A106KE05L | — | 6 | B3 D3
C901 | 1 | 470u / 63V | SMD Ø16×17,5 | EEVFK1J471M | «+» — пл.1 (+24V); минус — полоса | 7 | B1
C909 | 1 | 820u 25V | SMD Ø10×10,5 | EEEFT1E821AP | «+» — пл.1 (+12V); минус — полоса | 7 | C2
D301 D302 D501 D511 | 4 | TPD2E2U06DCKR | SC-70 | TPD2E2U06DCKR-TP | вывод 1 — точка / скос | 3 | C4 D3 D4
D303 | 1 | BAV170 | SOT-23 | BAV170 | K — пл.3; пл.1, 2 — аноды | 3 | C2
D521 D902 | 2 | SS56 | SMC | SS56 | K (полоса) — пл.1 | 3 | A2 C2
D601 D901 | 2 | SMBJ26CA-E3/52 | SMB | SMBJ26CA-E3/52 | нет (двунаправленный) | 3 | A1 A2
D711 D721 | 2 | SBRT15U100SP5 | PowerDI5 | SBRT15U100SP5-13 | K — широкая пл.1 (вывод 1) | 3 | B3 C3
F301 | 1 | PTC 0.10A / >=16V | 1206 | nSMD010 | — | 6 | D3
F501 F511 F521 | 3 | 1A | Littelfuse 451 | 0451001.MRL | — | 7 | A2 C4 D4
F711 | 1 | 6.3A | Littelfuse 451 | 045106.3MRL | — | 7 | A3
F721 F904 | 2 | 3A | Littelfuse 451 | 0451003.MRL | — | 7 | B2 C3
J401 | 1 | microSD | microSD | TF-01A | по контуру на шёлке | 8 | D2
L101 | 1 | 4.7u | FXL0630 | FXL0630-4R7-M | — | 7 | B3
L721 | 1 | 47u | SRP1265A | SRP1265A-470M | — | 7 | C3
L902 | 1 | 22u | FXL0630 | PSPMAA0604-220M-ANP | — | 7 | C2
Q501 Q511 | 2 | AO3400A | SOT-23 | AO3400A | 1 = G, 2 = S, 3 = D | 3 | C4 D4
Q521 | 1 | AO3422 | SOT-23 | AO3422 | 1 = G, 2 = S, 3 = D | 3 | A2
Q711 Q721 | 2 | BSC146N10LS5 | TDSON-8 | BSC146N10LS5 | 1 — точка; D — пл. 5–8 и большая | 3 | B3 C3
R101 R502 R512 R522 R602 R713 R723 | 7 | 100k 1% | 0603 | RC0603FR-07100KL | — | 4 | A2 A3 B3 C2 C3 C4 D4
R102 | 1 | 31.6k 1% | 0603 | 0603WAF3162T5E | — | 4 | C3
R201 R202 R203 R207 R208 R209 R210 R211 R212 R306 R405 R406 R407 R408 R410 R714 R724 | 17 | 10k 5% | 0805 | по номиналу, склад 70 | — | 5 | B2 B3 C1 C2 C3 C4 D1 D2 D3 D4
R204 R205 R206 R305 R307 R503 R513 R712 | 8 | 1k 1% | 0603 | RC0603FR-071KL | — | 4 | B3 C2 C4 D3 D4
R301 R302 | 2 | 4.7k 5% | 0805 | по номиналу, склад 72 | — | 5 | D1
R303 R304 R401 R402 R403 R404 R501 R511 R521 | 9 | 33 | 0603 | 0603WAF330JT5E | — | 4 | A3 C2 C4 D1 D2 D4
R601 R711 R721 | 3 | 10R 5% | 1206 | по номиналу, склад 41 | — | 6 | A2 B3 C4
R703 R908 | 2 | 47k 1% | 1206 | по номиналу, склад 61 | — | 6 | B2 C3
R715 | 1 | 0.027 1% >=1W | 2512 | LR123WF270MT4E | — | 6 | B4
R716 | 1 | 0.12 1% 3W 50ppm | 2512 | JER2512F3R120 | — | 6 | A4
R717 R727 | 2 | 316k 1% | 0603 | 0603WAF3163T5E | — | 4 | B3 D3
R718 R728 | 2 | 10k 1% | 0805 | по номиналу, склад 59 | — | 5 | C3 D3
R722 | 1 | 2.7k 1% | 0603 | 0603WAF2701T5E | — | 4 | D4
R725 | 1 | 0.047 1% >=1W | 2512 | HIXD25NR047F | — | 6 | D3
R726 | 1 | 0.43 1% >=0.25W | 1206 | RLH12FTCR430 | — | 6 | C4
R904 | 1 | 88.7k 0.1% | 0603 | RT0603BRD0788K7L | — | 4 | C2
R905 | 1 | 10k 0.1% | 0603 | RT0603BRD0710KL | — | 4 | C2
R907 | 1 | 470k 1% | 0603 | 0603WAF4703T5E | — | 4 | B2
U101 | 1 | ST1S10PHR | SOIC-8 EP | ST1S10PHR | вывод 1 — точка / скос | 2 | B2
U201 | 1 | ESP32-WROOM-32E-N4 | модуль | ESP32-WROOM-32E-N4 | вывод 1 — угол у левого края; антенна вверх | 8 | D1
U301 | 1 | PCF8563T/5 | SOIC-8 | PCF8563T/5,518 | вывод 1 — точка / скос | 2 | D2
U601 | 1 | UCC27524ADR | SOIC-8 | UCC27524ADR | вывод 1 — точка / скос | 2 | B2
U700 | 1 | SN74LVC1G08DBVR | SOT-23-5 | SN74LVC1G08DBVR | вывод 1 — точка / скос | 2 | C3
U710 U720 | 2 | AL8853S-13 | SOIC-8 | AL8853S-13 | вывод 1 — точка / скос | 2 | B3 D3
U902 | 1 | ST1S14PHR | SOIC-8 EP | ST1S14PHR | вывод 1 — точка / скос | 2 | B2
Y301 | 1 | 32.768k 12.5pF | SMD 3,2×1,5 | Q13FC13500004 | — | 7 | C2

Не ставить: C106 (DNP); TP101–TP103, TP301, TP901, TP902, NT711, NT712, NT721, NT722 — только медные площадки. «Шаг» — порядок пайки (расшифровка на схеме), «Зоны» — сетка A–D, 1–4 на схеме.

# GrowBox cheap-1 — схема установки выводных деталей (вид сверху)

# платы. Нижняя сторона (плата перевёрнута, зеркально): BT301

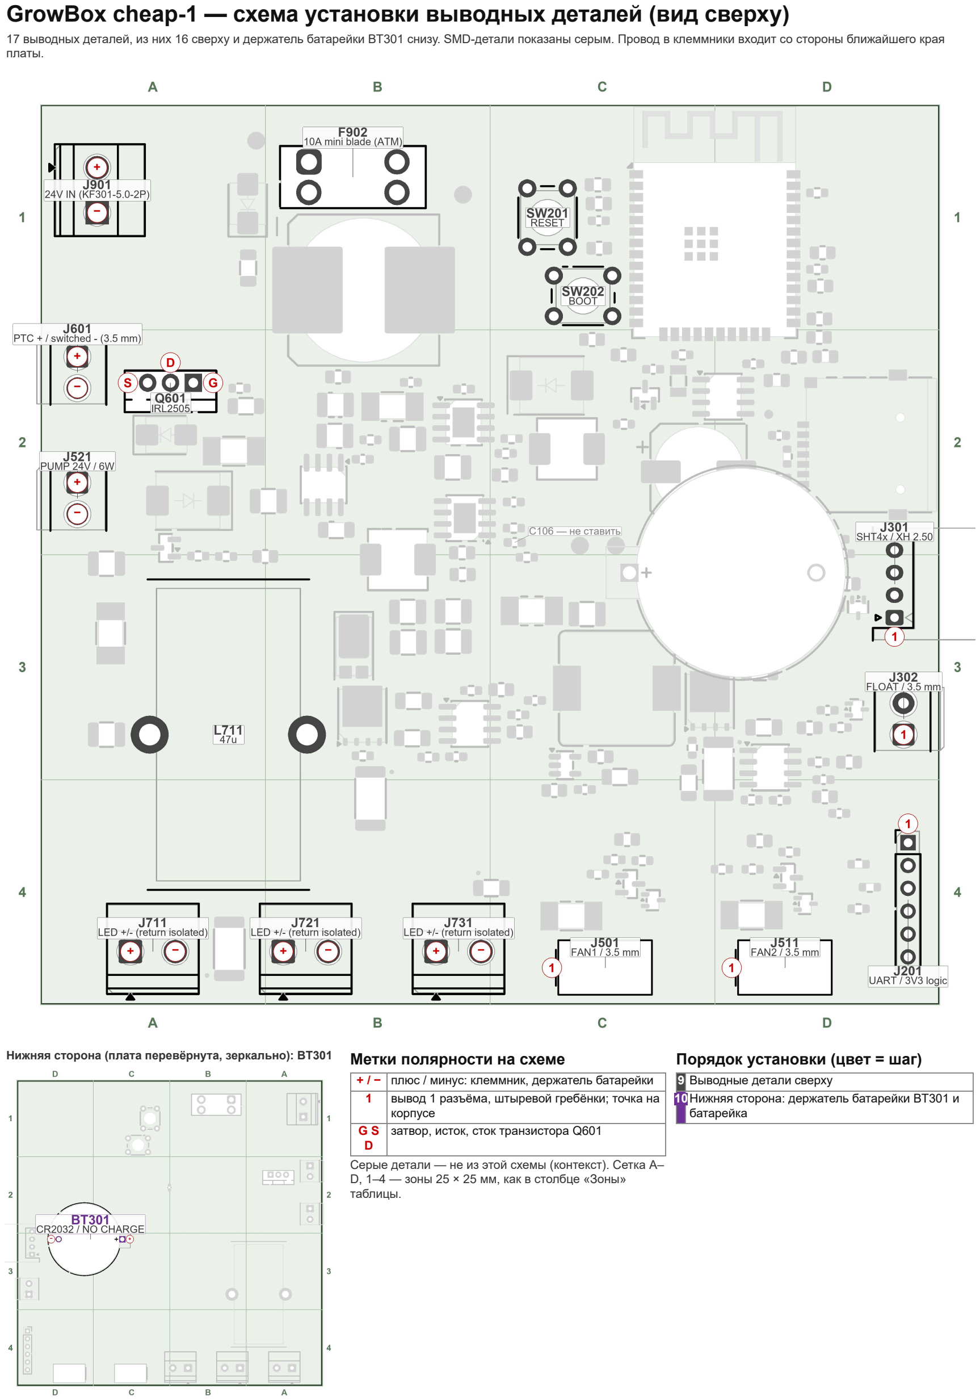
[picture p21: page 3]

17 выводных деталей, из них 16 сверху и держатель батарейки BT301 снизу. SMD-детали показаны серым. Провод в клеммники входит со стороны ближайшего края

### Метки полярности на схеме

+ / − плюс / минус: клеммник, держатель батарейки

### 1 вывод 1 разъёма, штыревой гребёнки; точка на

| корпусе
G S D | затвор, исток, сток транзистора Q601

Серые детали — не из этой схемы (контекст). Сетка A– D, 1–4 — зоны 25 × 25 мм, как в столбце «Зоны» таблицы.

### Порядок установки (цвет = шаг)

### 9 Выводные детали сверху

10Нижняя сторона: держатель батарейки BT301 и батарейка

# Выводные детали — позиции и MPN (17 шт., 15 строк)

Позиции | Шт. | Номинал | Корпус | MPN | Полярность / ориентация | Шаг | Зоны
BT301 (снизу) | 1 | CR2032 / NO CHARGE | держатель CR2032 | BS-07-A1BJ001 | «+» — пл.1 (RTC_VBAT), «−» — пл.2; снизу | 10 | D3
F902 | 1 | 10A mini blade (ATM) | держатель ATM | XF-508P-B-B | — | 9 | B1
J201 | 1 | UART / 3V3 logic | гребёнка 1×6 | 2.54-1x6P | вывод 1 — метка; 1=GND 2=VREF_3V3 3=PROG_TX_FROM_ESP 4=PROG_RX_TO_ESP 5=ESP_EN 6=ESP_IO0 | 9 | D4
J301 | 1 | SHT4x / XH 2.50 | JST XH 4, угловой | XH2.54-4P-90 | вывод 1 — метка; 1=SHT_3V3 2=GND 3=SHT_SDA_EXT 4=SHT_SCL_EXT | 9 | D3
J302 | 1 | FLOAT / 3.5 mm | клеммник 3,5 | FS1.5-02-350-2601R | вывод 1 — метка; 1=WATER_EXT 2=GND | 9 | D3
J501 | 1 | FAN1 / 3.5 mm | KK-254 4, прямой | KF2510-4P | вывод 1 — метка; 1=GND 2=FAN1_12V 3=FAN1_TACH_EXT 4=FAN1_PWM_EXT | 9 | C4
J511 | 1 | FAN2 / 3.5 mm | KK-254 4, прямой | KF2510-4P | вывод 1 — метка; 1=GND 2=FAN2_12V 3=FAN2_TACH_EXT 4=FAN2_PWM_EXT | 9 | D4
J521 | 1 | PUMP 24V / 6W | клеммник 3,5 | FS1.5-02-350-2601R | 1 = + (PUMP_24V), 2 = − (PUMP_DRAIN) | 9 | A2
J601 | 1 | PTC + / switched (3.5 mm) | клеммник 3,5 | FS1.5-02-350-2601R | 1 = + (+24V_LOADS), 2 = − (HEATER_DRAIN) | 9 | A2
J711 J721 J731 | 3 | LED +/ (return isolated) | клеммник 5,0 | KF301-5.0-2P | 1 = +, 2 = − (вход светильника) | 9 | A4 B4
J901 | 1 | 24V IN (KF301-5.0-2P) | клеммник 5,0 | KF301-5.0-2P | 1 = − (GND), 2 = + (+24V) | 9 | A1
L711 | 1 | 47u | тороид, стоя | DTMSS-27/0.047/15-V | — | 9 | A3
Q601 | 1 | IRL2505 | TO-220, стоя | IRL2505 | 1 = G, 2 = D, 3 = S; надпись к верху платы | 9 | A2
SW201 | 1 | RESET | кнопка 6×6×10 | 6X6X10MM Tact Switch | — | 9 | C1
SW202 | 1 | BOOT | кнопка 6×6×10 | 6X6X10MM Tact Switch | — | 9 | C1
BT301 (батарейка) | 1 | CR2032 | батарейка 20 мм | CR2032 | плюсом к плюсовому контакту держателя | 10 | —

F902: в держатель вставляется свой предохранитель 10 А (ATM mini) — после проверки платы, в закупку он не входит. Батарейку CR2032 тоже вставлять после проверки. Порядок: кнопки и гребёнка, разъёмы JST и KK, клеммники, F902, Q601, тороид L711 последним; BT301 — снизу.

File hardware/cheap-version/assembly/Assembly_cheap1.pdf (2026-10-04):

# GrowBox cheap-1 — инструкция по сборке

Плата cheapversion, 4 слоя, 100 × 100 мм, ручная пайка. Файлы платы: hardware/cheapversion/, перечень деталей — BOM_cheap1.csv, проверка включения — review/Bench_checklist_cheap1.md.
На плате 159 деталей для установки: 142 для поверхностного монтажа и 17 выводных (из них одна с нижней стороны). Контрольные точки TP101–TP103, TP301, TP901, TP902 и пары NT (NT711, NT712, NT721, NT722) — только медные площадки, ничего не ставить; конденсатор C106 помечен DNP и тоже не ставится (11 позиций). Всего одна SMD-деталь на нижней стороне — C911.
Как пользоваться: сначала страница «Главное о полярности», затем шаги 1–10 по порядку. Каждый шаг показывает на общем плане платы, где стоят его детали, и перечисляет их по номиналам. Подробные рисунки — «плоскости» A1–D4 (по 25 × 25 мм, подписаны позиции и номиналы); полярность и ориентация сложных деталей — карточки в конце.

## Шаги и цвета

1 Нижняя сторона: C911 (1)
2 Микросхемы (7)
3 Транзисторы и диоды SMD (16)
4 Резисторы и конденсаторы 0603 (47) 5 Резисторы и конденсаторы 0805 (28)
6 Резисторы и конденсаторы 1206, 1210, | 2512; PTC-предохранитель F301 (29)
7 Индуктивности, предохранители | Littelfuse, кварц, электролиты C901 и C909 (12)

8 Модуль ESP32 и разъём microSD (2) 9 Выводные детали сверху (16)
10 Нижняя сторона: держатель батарейки | BT301 и батарейка (1)

Цвет площадок на рисунках = шаг.

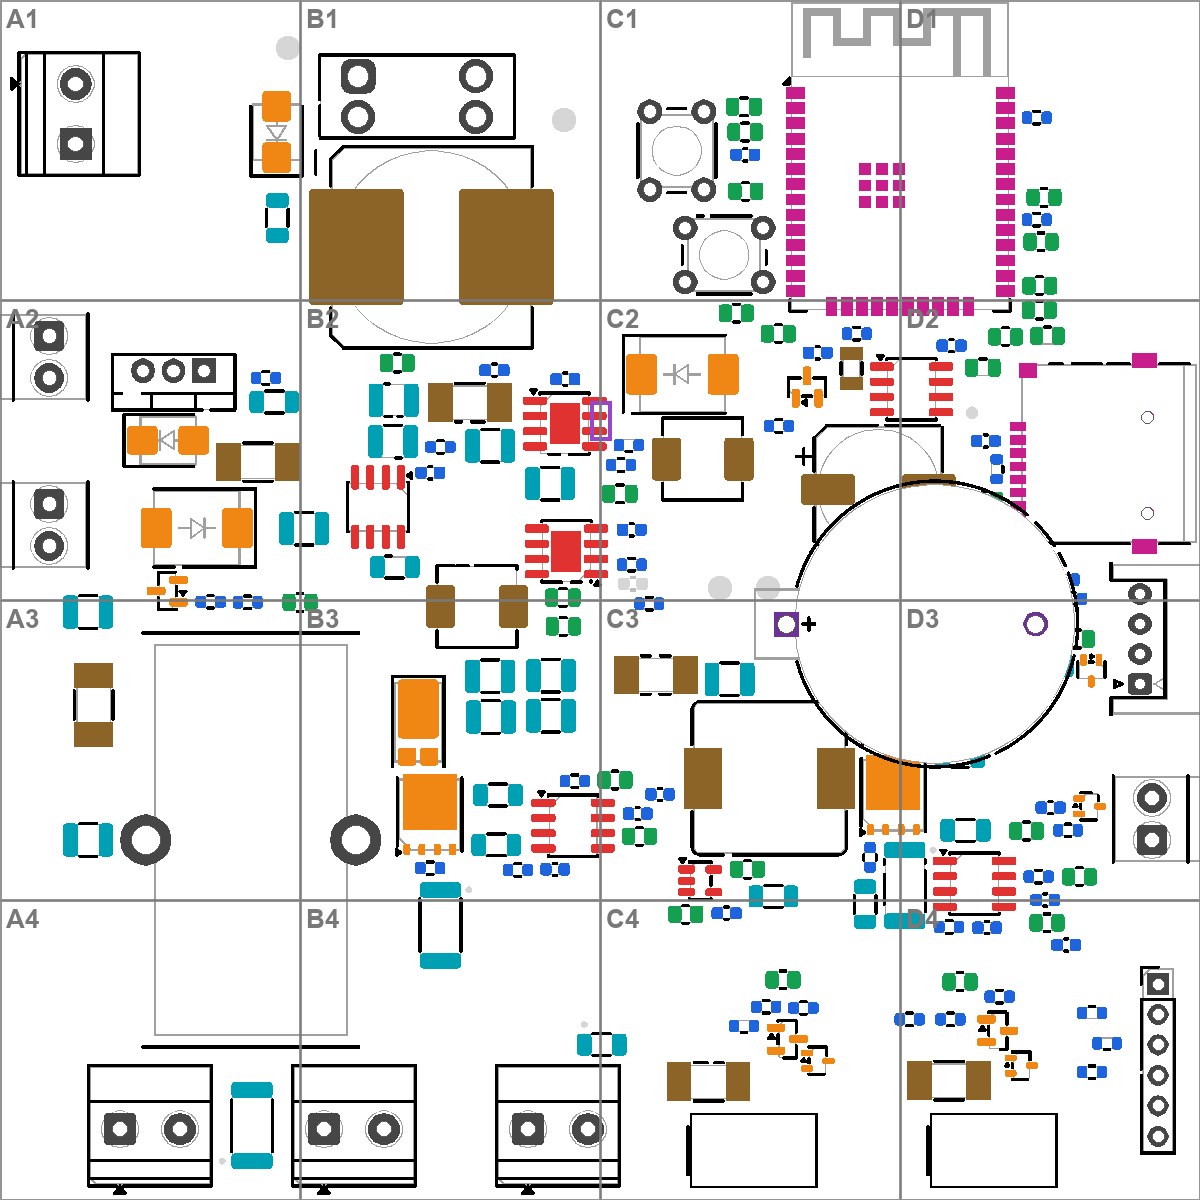
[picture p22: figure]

## Общие правила

1. Перед пайкой сверить позиции с BOM; керамические конденсаторы не маркируются — держать каждый номинал в подписанном пакетике.
2. В одном корпусе бывают разные номиналы (1210: 10 мкФ на 35, 50 и 100 В; индуктивности L101 и L902; предохранители Littelfuse 1, 3 и 6,3 А; шунты 2512) — на шаге они выделены.
3. Антистатика для микросхем и транзисторов. Флюс, чистая жала; ориентиры: паяльник 320–350 °C, фен 300–350 °C (по припою и пасте).
4. После каждого шага осмотреть пайку: перемычки между выводами, непропай, смещение, полярность. Использовать некорродирующий флюс, остатки смыть спиртом.
5. Выводные детали — после всех SMD, от низких к высоким. Тороид L711 и электролиты — последними из крупных.

GrowBox cheap-1 — сборка — стр. 1

# Главное о полярности и ориентации

Эти детали нельзя поставить наоборот. На всех рисунках платы красный кружок показывает нужный вывод: K — катод, + — плюс, 1 — вывод 1, G, S, D — затвор, исток, сток. Если метка на детали не совпадает с красным кружком — деталь развёрнута неверно.

Деталь | Что проверить
Электролиты C901, C909 | плюс — площадка 1: C901 к +24V, C909 к +12V; минус — к земле (полоса на корпусе отмечает минус)
Диоды SS56: D521, D902 | катод (полоса) — площадка 1: D521 к PUMP_24V, D902 к BUCK12_SW
Диоды SBRT15U100SP5: D711, D721 | катод — широкая площадка (вывод 1): LED1_OUT / LED2_OUT; два узких вывода — анод (SW)
Диод BAV170: D303 | вывод 3 — общий катод (RTC_VDD); выводы 1 и 2 — аноды (+3V3, RTC_VBAT_R)
Микросхемы U101, U301, U601, U700, U710, U720, U902, ESP32 U201 | вывод 1 — точка или скос на корпусе против метки на шёлке и красного «1» на плане
ИС защиты D301, D302, D501, D511 | вывод 1 — метка на корпусе
Транзисторы SOT-23: Q501, Q511, Q521 | вывод 1 — затвор, 2 — исток, 3 — сток; вывод 3 один на своей стороне корпуса
Q711, Q721 (BSC146N10LS5) | вывод 1 — точка на корпусе (исток), большая площадка и выводы 5–8 со стороны стока
Q601 (IRL2505, TO-220) | ножки: 1 — затвор, 2 — сток, 3 — исток (по порядку на плате); металлическая пластина — как нарисовано на шёлке
Клеммники | провод входит со стороны ближайшего края платы. J901: GND / +24V; J601: +24V_LOADS / HEATER_DRAIN; J521: PUMP_24V / PUMP_DRAIN; J711–J731: + LED1_OUT / − LED1_RETURN
Разъёмы J201, J301, J501, J511 | ключ и вывод 1 — по рисунку на шёлке; порядок выводов в карточках
Батарейный держатель BT301 (снизу) и CR2032 | плюс — площадка 1 (RTC_VBAT); батарейка плюсом к плюсовому контакту
Без полярности | керамические конденсаторы, резисторы, индуктивности и предохранители, кварц Y301, диоды SMBJ26CA (D601, D901 — двунаправленные), кнопки

Нижняя сторона: C911 (100 нФ, без полярности) и держатель BT301 ставятся с обратной стороны платы; на рисунках нижней стороны плата показана зеркально, как её видно при переворачивании.

GrowBox cheap-1 — главное о полярности и ориентации — стр. 2

# Шаг 1. Нижняя сторона: C911

1 деталей. Вид снизу (зеркально).
Плата вверх нижней стороной. Единственная SMD-деталь снизу — C911 (100 нФ, 0603), прямо под выводами 6 и 7 микросхемы U902 (на плане пунктирной рамкой). Полярности нет. Пока на нижней стороне ничего не выступает, плата лежит ровно.

C911 стоит поперёк, под выводами VIN и GND микросхемы U902 (она сверху). Это высокочастотная развязка входа: не заменять большим конденсатором и не убирать.

Позиции | Шт. | Номинал | Корпус | MPN | Откуда | Плоскости
C911 | 1 | 100n 50V | 0603 | CL10B104KB8NNNC | склад (№ 54) | C2

Шаг 1 — стр. 3

# Шаг 2. Микросхемы

7 деталей. Вид сверху.
Микросхемы. Вывод 1 — точка или скос на корпусе против метки на шёлке (чёрный треугольник или точка) и красного «1» на рисунках. Сначала припаять два крайних вывода, проверить положение, потом остальные.

## На что смотреть

U902 и U101 (SOIC-8 с площадкой EP): под корпусом теплоотводящая площадка, она же земля — припаять феном с пастой.
U601 (UCC27524ADR): вывод 1 присоединён к цепи +12V, выводы 3, 4, 8 — к земле, вывод 5 свободен.
U700 — SOT-23-5, вывод 1 в углу с меткой. U710, U720 (AL8853S) — одинаковые, U301 — часы PCF8563T.

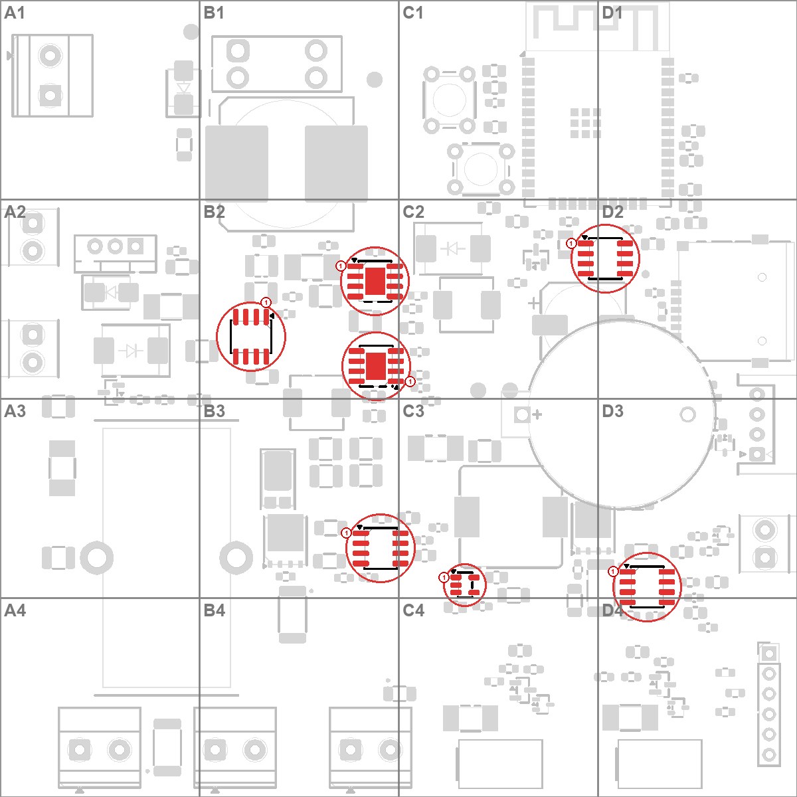
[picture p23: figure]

Позиции | Шт. | Номинал | Корпус | MPN | Откуда | Плоскости
U101 | 1 | ST1S10PHR | SOIC-8 с площадкой EP | ST1S10PHR | склад (№ 27) | B2
U902 | 1 | ST1S14PHR | SOIC-8 с площадкой EP | ST1S14PHR | склад (№ 26) | B2
U710 U720 | 2 | AL8853S-13 | SOIC-8 | AL8853S-13 | докупка | B3 D3
U301 | 1 | PCF8563T/5 | SOIC-8 | PCF8563T/5,518 | докупка | D2
U601 | 1 | UCC27524ADR | SOIC-8 | UCC27524ADR | докупка | B2
U700 | 1 | SN74LVC1G08DBVR | SOT-23-5 | SN74LVC1G08DBVR | докупка | C3

Шаг 2 — стр. 4

# Шаг 3. Транзисторы и диоды SMD

16 деталей. Вид сверху.
Транзисторы и диоды SMD. У большинства есть полярность: смотреть красные метки K (катод), G/S/D (выводы), 1 (вывод
1) на рисунках и в карточках.

## Особенности

D601 и D901 (SMBJ26CA) — двунаправленные, ставить любой стороной. D711, D721 (PowerDI5): катод — широкая площадка. SS56 (D521, D902): катод — полоса. Q711, Q721 (TDSON-8): вывод 1 — точка на корпусе. Детали по карточкам в конце.

Позиции | Шт. | Номинал | Корпус | MPN | Откуда | Плоскости
D601 D901 | 2 | SMBJ26CA-E3/52 | SMB (DO-214AA) | SMBJ26CA-E3/52 | докупка | A1 A2
D521 D902 | 2 | SS56 | SMC (DO-214AB) | SS56 | склад (№ 20) | A2 C2
D711 D721 | 2 | SBRT15U100SP5 | PowerDI5 | SBRT15U100SP5-13 | склад (№ 8) | B3 C3
D303 | 1 | BAV170 | SOT-23 | BAV170 | докупка | C2
D301 D302 D501 D511 | 4 | TPD2E2U06DCKR | SOT-323 (SC-70) | TPD2E2U06DCKR-TP | докупка | C4 D3 D4
Q501 Q511 | 2 | AO3400A | SOT-23 | AO3400A | докупка | C4 D4
Q521 | 1 | AO3422 | SOT-23 | AO3422 | докупка | A2
Q711 Q721 | 2 | BSC146N10LS5 | TDSON-8 | BSC146N10LS5 | склад (№ 112) | B3 C3

Шаг 3 — стр. 5

# Шаг 4. Резисторы и конденсаторы 0603

47 деталей. Вид сверху.
Резисторы и конденсаторы 0603 (1,6 × 0,8 мм). Полярности нет. Ставить сразу все детали одного номинала, номинал сверять с таблицей: керамика не маркируется.

## Совет

Паять по плоскостям A1–D4: на каждой написан номинал рядом с позицией.

Позиции | Шт. | Номинал | Корпус | MPN | Откуда | Плоскости
C102 C202 C301 C303 C402 C601 C700 C907 C908 | 9 | 100n 50V | 0603 | CL10B104KB8NNNC | склад (№ 54) | B2 C1 C2 C4 D2 D3
C712 C713 C722 C723 | 4 | 100p | 0603 | CL10C101JB8NNNC | докупка | B3 C3 D4
C304 | 1 | 18p 50V | 0603 | CL10C180JB8NNNC | докупка | C2
C714 C724 | 2 | 220n | 0603 | CL10B224KB8NNNC | докупка | C3 D4
R101 R502 R512 R522 R602 R713 R723 | 7 | 100k 1% | 0603 | RC0603FR-07100KL | склад (№ 55) | A2 A3 B3 C2 C3 C4 D4
R905 | 1 | 10k 0.1% | 0603 | RT0603BRD0710KL | докупка | C2
R204 R205 R206 R305 R307 R503 R513 R712 | 8 | 1k 1% | 0603 | RC0603FR-071KL | склад (№ 62) | B3 C2 C4 D3 D4
R722 | 1 | 2.7k 1% | 0603 | 0603WAF2701T5E | докупка | D4
R102 | 1 | 31.6k 1% | 0603 | 0603WAF3162T5E | докупка | C3
R717 R727 | 2 | 316k 1% | 0603 | 0603WAF3163T5E | докупка | B3 D3
R303 R304 R401 R402 R403 R404 R501 R511 R521 | 9 | 33 | 0603 | 0603WAF330JT5E | докупка | A3 C2 C4 D1 D2 D4
R907 | 1 | 470k 1% | 0603 | 0603WAF4703T5E | докупка | B2
R904 | 1 | 88.7k 0.1% | 0603 | RT0603BRD0788K7L | докупка | C2

Шаг 4 — стр. 6

# Шаг 5. Резисторы и конденсаторы 0805

28 деталей. Вид сверху.
Резисторы и конденсаторы 0805 (2,0 × 1,25 мм). Полярности нет. Два разных 10 кОм: 5 % (R201 R202 R203 R207…) и 1 % 0805 (R718, R728) — по таблице.

## Совет

C103, C203, C302 — 2,2 мкФ 16 В; C104, C105, C401 — 22 мкФ 10 В; C201 — 10 мкФ 16 В.

Позиции | Шт. | Номинал | Корпус | MPN | Откуда | Плоскости
C201 | 1 | 10u 16V | 0805 | CL21A106KAYNNNE | склад (№ 58) | C1
C103 C203 C302 | 3 | 2.2u 16V | 0805 | CL21A225KOFNNNE | склад (№ 57) | C1 C2 D3
C104 C105 C401 | 3 | 22u / 10V | 0805 | CL21A226KPCLRNC | склад (№ 7) | B2 B3 D2
R718 R728 | 2 | 10k 1% | 0805 | | склад (№ 59) | C3 D3
R201 R202 R203 R207 R208 R209 R210 R211 R212 R306 R405 R406 R407 R408 R410 R714 R724 | 17 | 10k 5% | 0805 | | склад (№ 70) | B2 B3 C1 C2 C3 C4 D1 D2 D3 D4
R301 R302 | 2 | 4.7k 5% | 0805 | | склад (№ 72) | D1

Шаг 5 — стр. 7

# Шаг 6. Резисторы и конденсаторы 1206, 1210, 2512; PTC-предохранитель F301

29 деталей. Вид сверху.
Крупные 1206, 1210, 2512. Полярности нет. В 1210 три разных 10 мкФ (35 В, 50 В, 100 В X7S) — внимательно по таблице. Шунты 2512: R715 0,027 Ом, R716 0,12 Ом, R725 0,047 Ом; R726 0,43 Ом — 1206.

## Не перепутать

10 мкФ 35 В: C101, C602, C910. 10 мкФ 50 В: C521, C710, C715, C725, C905, C906. 10 мкФ 100 В X7S: C716–C719, C726–C728 (выход LED). 2,2 мкФ 50 В 1206: C711, C721, C902.

Позиции | Шт. | Номинал | Корпус | MPN | Откуда | Плоскости
C711 C721 C902 | 3 | 2.2u 50V | 1206 | 12065C225KATM-HW | склад (№ 3) | A1 B3 D3
C521 | 1 | 10u / 50V | 1210 | CL32B106KBJNNNE | склад (№ 47) | B2
C716 C717 C718 C719 C726 C727 C728 | 7 | 10u 100V | 1210 | GRM32EC72A106KE05L | докупка | B3 D3
C101 C602 C910 | 3 | 10u 35V | 1210 | CL32A106KLULNNE | склад (№ 6) | B2 C2
C710 C715 C725 C905 C906 | 5 | 10u 50V | 1210 | CL32B106KBJNNNE | склад (№ 47) | A3 B2 C3
F301 | 1 | PTC 0.10A / >=16V | 1206 | nSMD010 | докупка | D3
R726 | 1 | 0.43 1% >=0.25W | 1206 | RLH12FTCR430 | докупка | C4
R601 R711 R721 | 3 | 10R 5% | 1206 | | склад (№ 41) | A2 B3 C4
R703 R908 | 2 | 47k 1% | 1206 | | склад (№ 61) | B2 C3
R715 | 1 | 0.027 1% >=1W | 2512 | LR123WF270MT4E | докупка | B4
R725 | 1 | 0.047 1% >=1W | 2512 | HIXD25NR047F | докупка | D3
R716 | 1 | 0.12 1% 3W 50ppm | 2512 | JER2512F3R120 | докупка | A4

Шаг 6 — стр. 8

Шаг 7. Индуктивности, предохранители Littelfuse, кварц,

# электролиты C901 и C909

12 деталей. Вид сверху.
Индуктивности (L101 4,7 мкГн и L902 22 мкГн в одинаковых корпусах — не перепутать), предохранители Littelfuse (1 А, 3 А и 6,3 А — одинаковый корпус), кварц Y301 (без полярности), SMD-электролиты C901 и C909 (полярность!). Электролиты — в последнюю очередь на этом шаге.

## Не перепутать

Предохранители: F501, F511, F521 — 1 А; F721, F904 — 3 А; F711 — 6,3 А; F301 (1206) — PTC 0,1 А.
C901 — 470 мкФ 63 В, C909 — 820 мкФ 25 В: плюс — площадка 1.

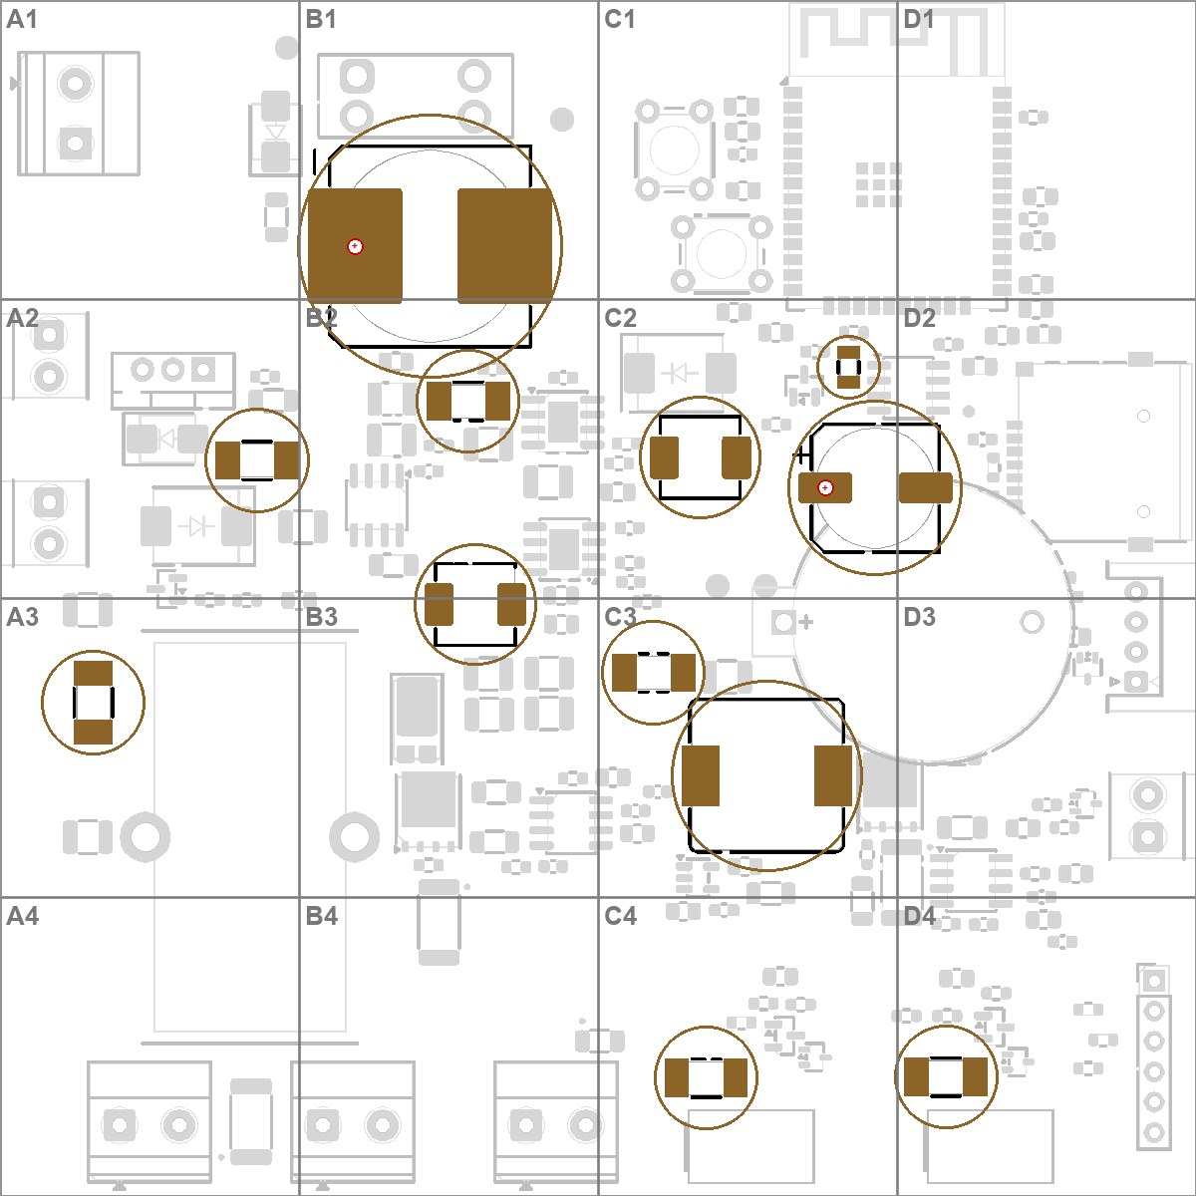
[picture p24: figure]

Позиции | Шт. | Номинал | Корпус | MPN | Откуда | Плоскости
C909 | 1 | 820u 25V | электролит SMD Ø10×10,5 | EEEFT1E821AP | склад (№ 14) | C2
C901 | 1 | 470u / 63V | электролит SMD Ø16×17,5 | EEVFK1J471M | склад (№ 13) | B1
F501 F511 F521 | 3 | 1A / 0451001.MRL | Littelfuse 451 (SMD) | 0451001.MRL | докупка | A2 C4 D4
F721 F904 | 2 | 3A / 0451003.MRL | Littelfuse 451 (SMD) | 0451003.MRL | докупка | B2 C3
F711 | 1 | 6.3A / 045106.3MRL | Littelfuse 451 (SMD) | 045106.3MRL | докупка | A3
L721 | 1 | 47u SRP1265A-470M | SRP1265A (SMD) | SRP1265A-470M | докупка | C3
L902 | 1 | 22u PSPMAA0604-220M | FXL0630 (SMD) | PSPMAA0604-220M-ANP | докупка | C2
L101 | 1 | 4.7u FXL0630-4R7-M | FXL0630 (SMD) | FXL0630-4R7-M | докупка | B3
Y301 | 1 | 32.768k 12.5pF | кварц SMD 3,2×1,5 | Q13FC13500004 | докупка | C2

Шаг 7 — стр. 9

# Шаг 8. Модуль ESP32 и разъём microSD

2 деталей. Вид сверху.
Модуль ESP32 U201 (вывод 1 в углу, антенна — к верхнему краю платы, где под ней нет меди) и разъём microSD J401 — по контуру на шёлке. У модуля площадка заземления под корпусом; паять феном или распаять по краю и прогреть центр.

## J401 microSD

Экран разъёма (вывод SH) — в металлизированные отверстия, припаять все; контакты карты — SMD.

Позиции | Шт. | Номинал | Корпус | MPN | Откуда | Плоскости
J401 | 1 | HRO TF-01A | microSD HRO TF-01A | TF-01A | докупка | D2
U201 | 1 | ESP32-WROOM-32E-N4 | модуль ESP32-WROOM-32E | ESP32-WROOM-32E-N4 | докупка | D1

Шаг 8 — стр. 10

# Шаг 9. Выводные детали сверху

16 деталей. Вид сверху.
Выводные детали. Порядок: кнопки и штыревая гребёнка, разъёмы JST и KK, клеммники, держатель предохранителя F902, транзистор Q601, тороид L711 — последним. Клеммники: провод входит со стороны ближайшего края платы.

## Особенности

L711 (тороид DTMSS-27, 47 мкГн, 15 А) ставится стоя на ребре: провода Ø1,9 мм в отверстия, зазор между тороидом и платой не больше 2 мм, лишнюю длину выводов подрезать после пайки; корпус закрепить клеем. Q601 (TO-220) стоя, без радиатора. В F902 предохранитель 10 А (ATM mini) вставляется после проверки платы.

Позиции | Шт. | Номинал | Корпус | MPN | Откуда | Плоскости
F902 | 1 | 10A mini blade (ATM) | держатель ATM mini | XF-508P-B-B | докупка | B1
J301 | 1 | SHT4x / XH 2.50 | JST XH 4 pin, угловой | XH2.54-4P-90 | склад (№ 90) | D3
J501 | 1 | FAN1 / 3.5 mm | KK-254 4 pin, прямой | KF2510-4P | склад (№ 87) | C4
J511 | 1 | FAN2 / 3.5 mm | KK-254 4 pin, прямой | KF2510-4P | склад (№ 87) | D4
J201 | 1 | UART / 3V3 logic | штыревая гребёнка 1×6, шаг 2,54 | 2.54-1x6P | докупка | D4
J901 | 1 | 24V IN (KF301-5.0-2P) | клеммник KF301 2 pin, шаг 5,0 | KF301-5.0-2P | склад (№ 93) | A1
J711 J721 J731 | 3 | LED +/ (return isolated) | клеммник 2 pin, шаг 5,0 | KF301-5.0-2P | склад (№ 93) | A4 B4
J302 | 1 | FLOAT / 3.5 mm | клеммник 2 pin, шаг 3,5 | FS1.5-02-350-2601R | склад (№ 86) | D3
J601 | 1 | PTC + / switched (3.5 mm) | клеммник 2 pin, шаг 3,5 | FS1.5-02-350-2601R | склад (№ 86) | A2
J521 | 1 | PUMP 24V / 6W | клеммник 2 pin, шаг 3,5 | FS1.5-02-350-2601R | склад (№ 86) | A2
L711 | 1 | 47u DTMSS-27/0.047/15-V | тороид Ø32,5 мм, стоя | DTMSS-27/0.047/15-V | склад (№ 12) | A3
Q601 | 1 | IRL2505 | TO-220, стоя | IRL2505 | склад (№ 78) | A2
SW202 | 1 | BOOT | кнопка 6×6×10, выводная | 6X6X10MM Tact Switch | склад (№ 95) | C1
SW201 | 1 | RESET | кнопка 6×6×10, выводная | 6X6X10MM Tact Switch | склад (№ 95) | C1

Шаг 9 — стр. 11

# Шаг 10. Нижняя сторона: держатель батарейки BT301 и батарейка

1 деталей. Вид снизу (зеркально).
Нижняя сторона: держатель батарейки BT301 — контакты в отверстия, пайка сверху (на плане плата повёрнута). Батарейку CR2032 вставить после проверки платы.

BT301 — единственная выводная деталь снизу. Плюс батарейки — к плюсовому контакту держателя (площадка 1).

Позиции | Шт. | Номинал | Корпус | MPN | Откуда | Плоскости
BT301 | 1 | CR2032 / NO CHARGE | держатель CR2032 | BS-07-A1BJ001 | докупка | D3

Шаг 10 — стр. 12

# Плоскость A1

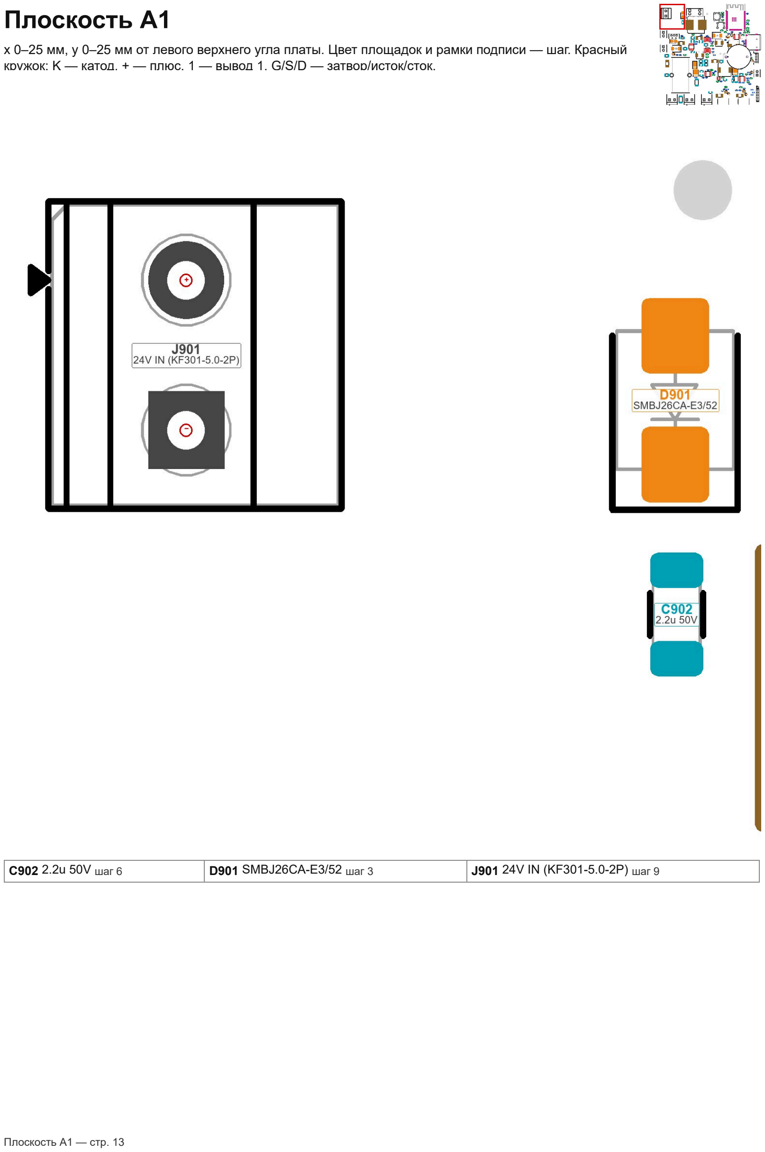
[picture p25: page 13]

x 0–25 мм, y 0–25 мм от левого верхнего угла платы. Цвет площадок и рамки подписи — шаг. Красный кружок: K — катод, + — плюс, 1 — вывод 1, G/S/D — затвор/исток/сток.

C902 2.2u 50V шаг 6 | D901 SMBJ26CA-E3/52 шаг 3 | J901 24V IN (KF301-5.0-2P) шаг 9

Плоскость A1 — стр. 13

# Плоскость B1

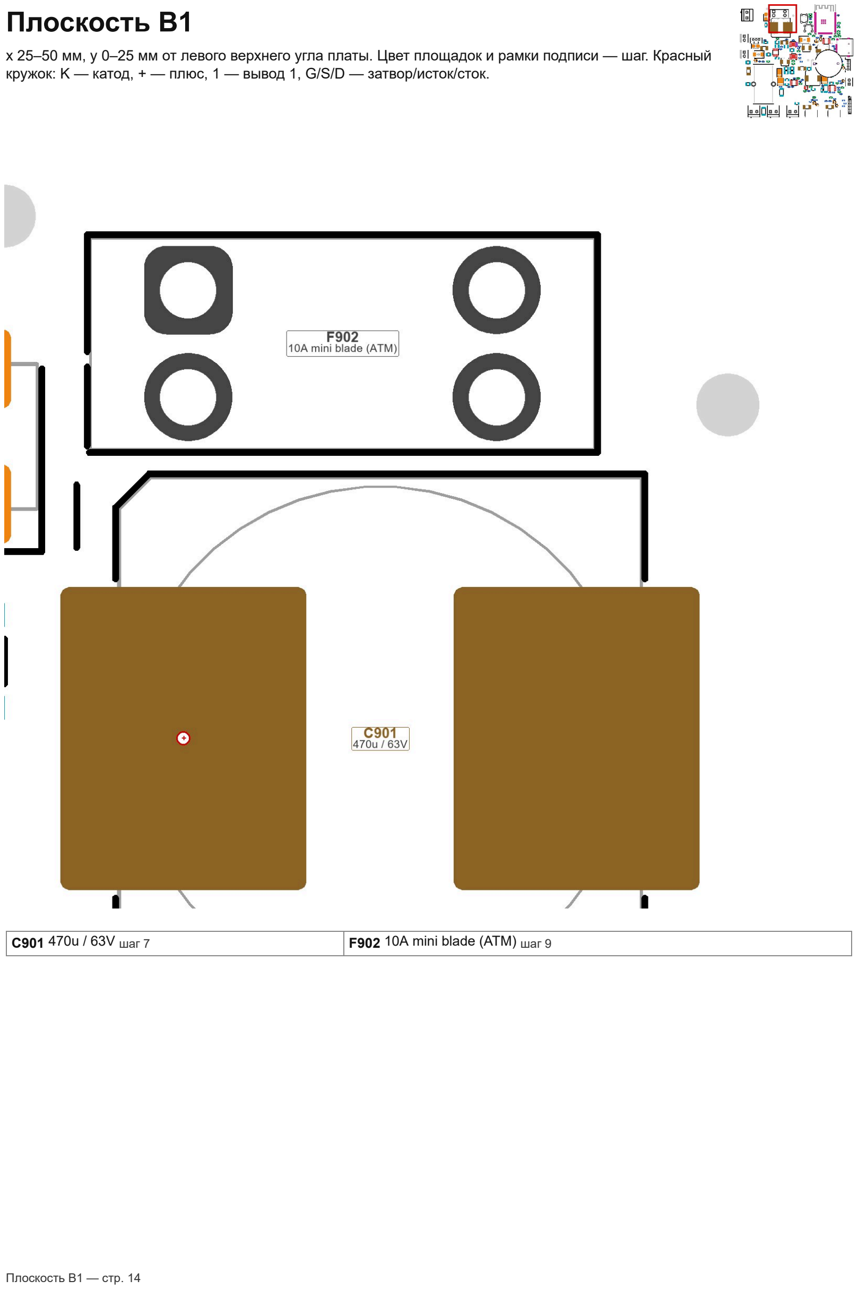
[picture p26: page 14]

x 25–50 мм, y 0–25 мм от левого верхнего угла платы. Цвет площадок и рамки подписи — шаг. Красный кружок: K — катод, + — плюс, 1 — вывод 1, G/S/D — затвор/исток/сток.

C901 470u / 63V шаг 7 | F902 10A mini blade (ATM) шаг 9

Плоскость B1 — стр. 14

# Плоскость C1

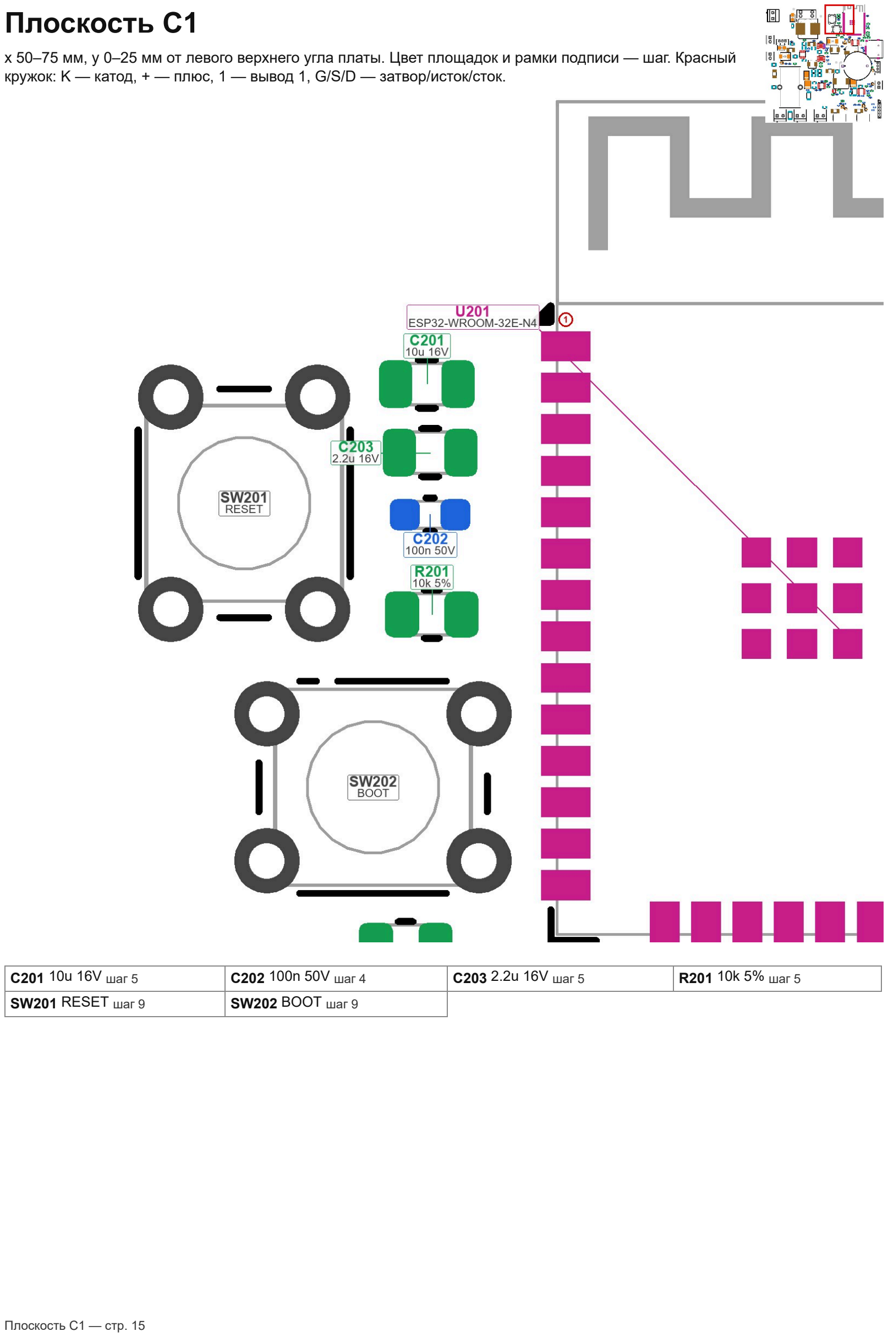
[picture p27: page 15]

x 50–75 мм, y 0–25 мм от левого верхнего угла платы. Цвет площадок и рамки подписи — шаг. Красный кружок: K — катод, + — плюс, 1 — вывод 1, G/S/D — затвор/исток/сток.

C201 10u 16V шаг 5 | C202 100n 50V шаг 4 | C203 2.2u 16V шаг 5 | R201 10k 5% шаг 5
SW201 RESET шаг 9 | SW202 BOOT шаг 9

Плоскость C1 — стр. 15

# Плоскость D1

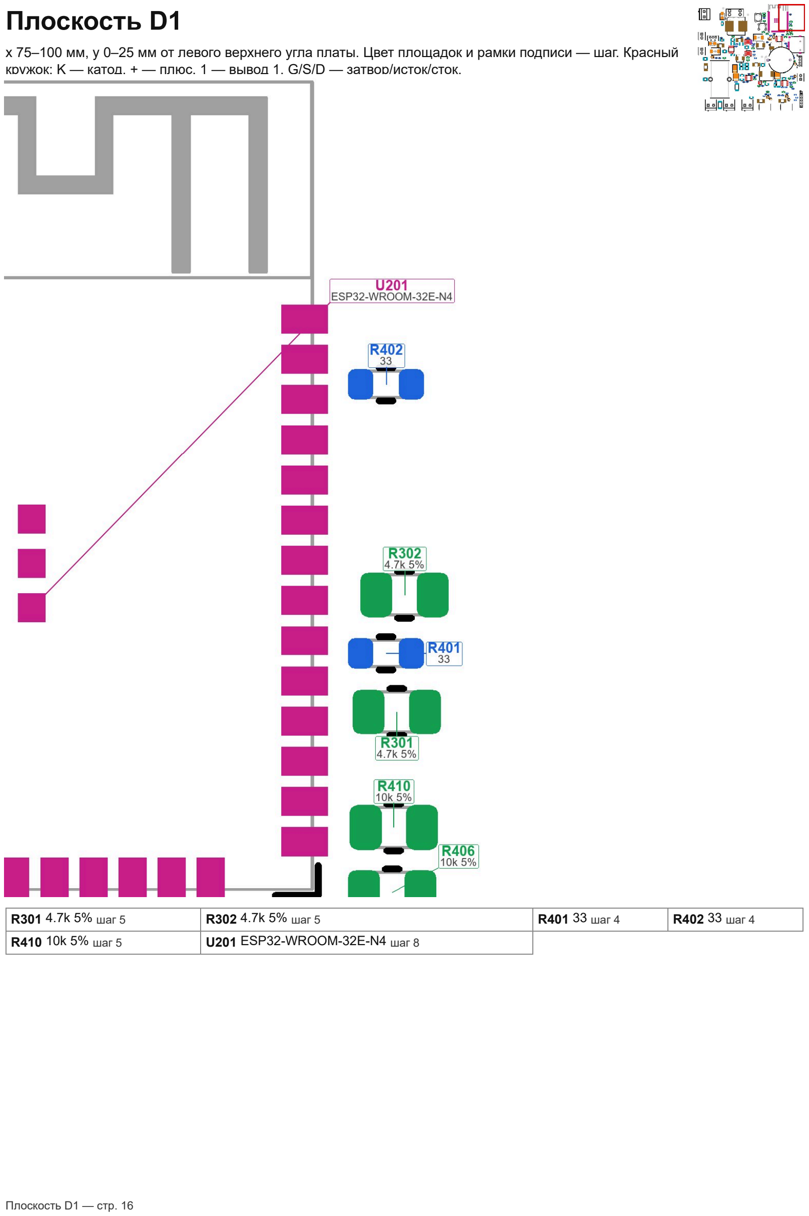
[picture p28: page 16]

x 75–100 мм, y 0–25 мм от левого верхнего угла платы. Цвет площадок и рамки подписи — шаг. Красный кружок: K — катод, + — плюс, 1 — вывод 1, G/S/D — затвор/исток/сток.

R301 4.7k 5% шаг 5 | R302 4.7k 5% шаг 5 | R401 33 шаг 4 | R402 33 шаг 4
R410 10k 5% шаг 5 | U201 ESP32-WROOM-32E-N4 шаг 8

Плоскость D1 — стр. 16

# Плоскость A2

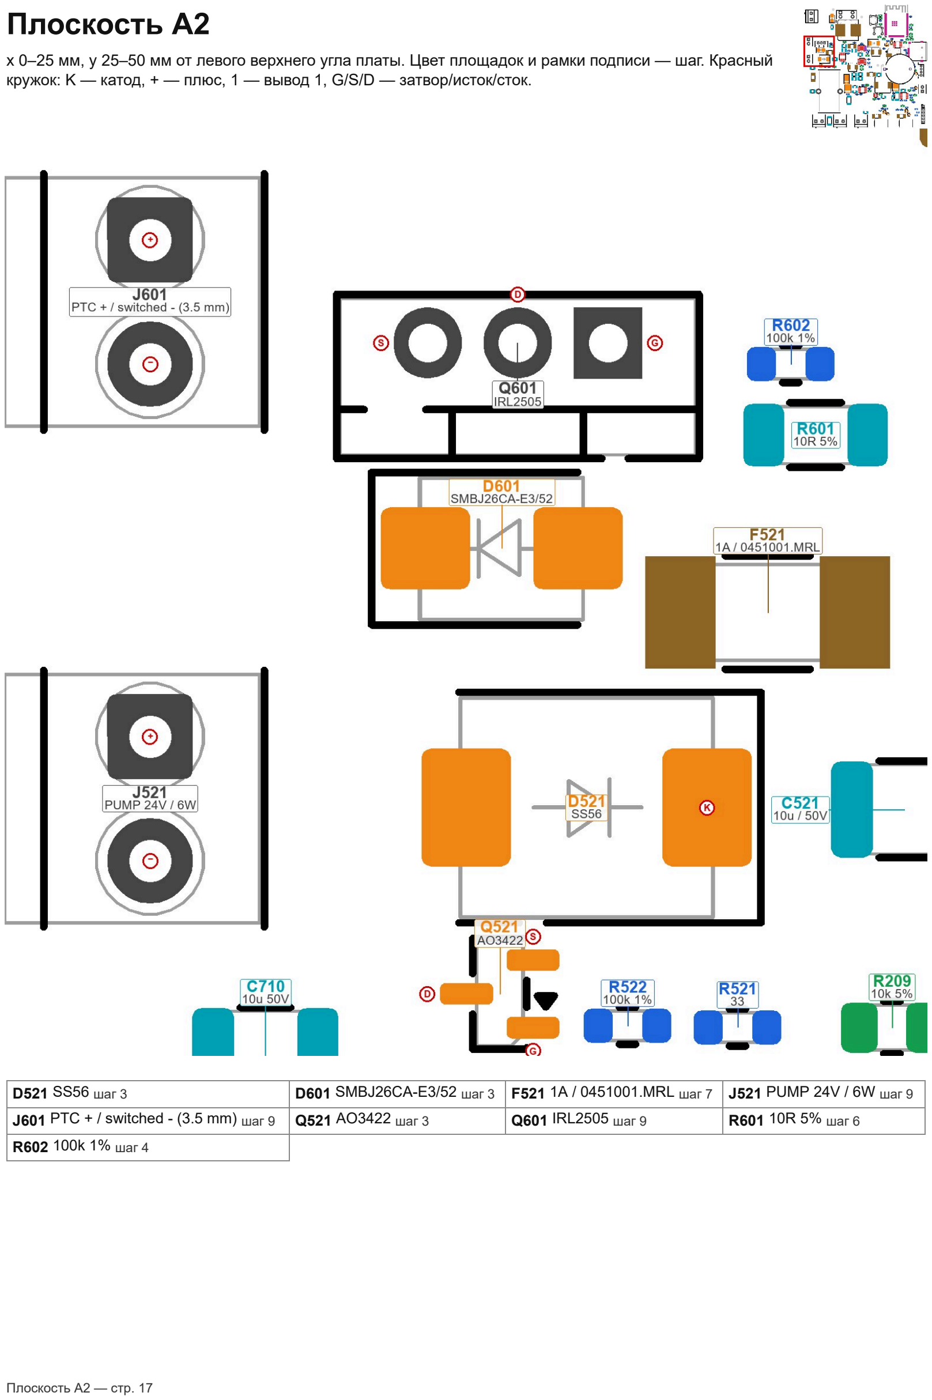
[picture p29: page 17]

x 0–25 мм, y 25–50 мм от левого верхнего угла платы. Цвет площадок и рамки подписи — шаг. Красный кружок: K — катод, + — плюс, 1 — вывод 1, G/S/D — затвор/исток/сток.

D521 SS56 шаг 3 | D601 SMBJ26CA-E3/52 шаг 3 | F521 1A / 0451001.MRL шаг 7 | J521 PUMP 24V / 6W шаг 9
J601 PTC + / switched (3.5 mm) шаг 9 | Q521 AO3422 шаг 3 | Q601 IRL2505 шаг 9 | R601 10R 5% шаг 6
R602 100k 1% шаг 4

Плоскость A2 — стр. 17

# Плоскость B2

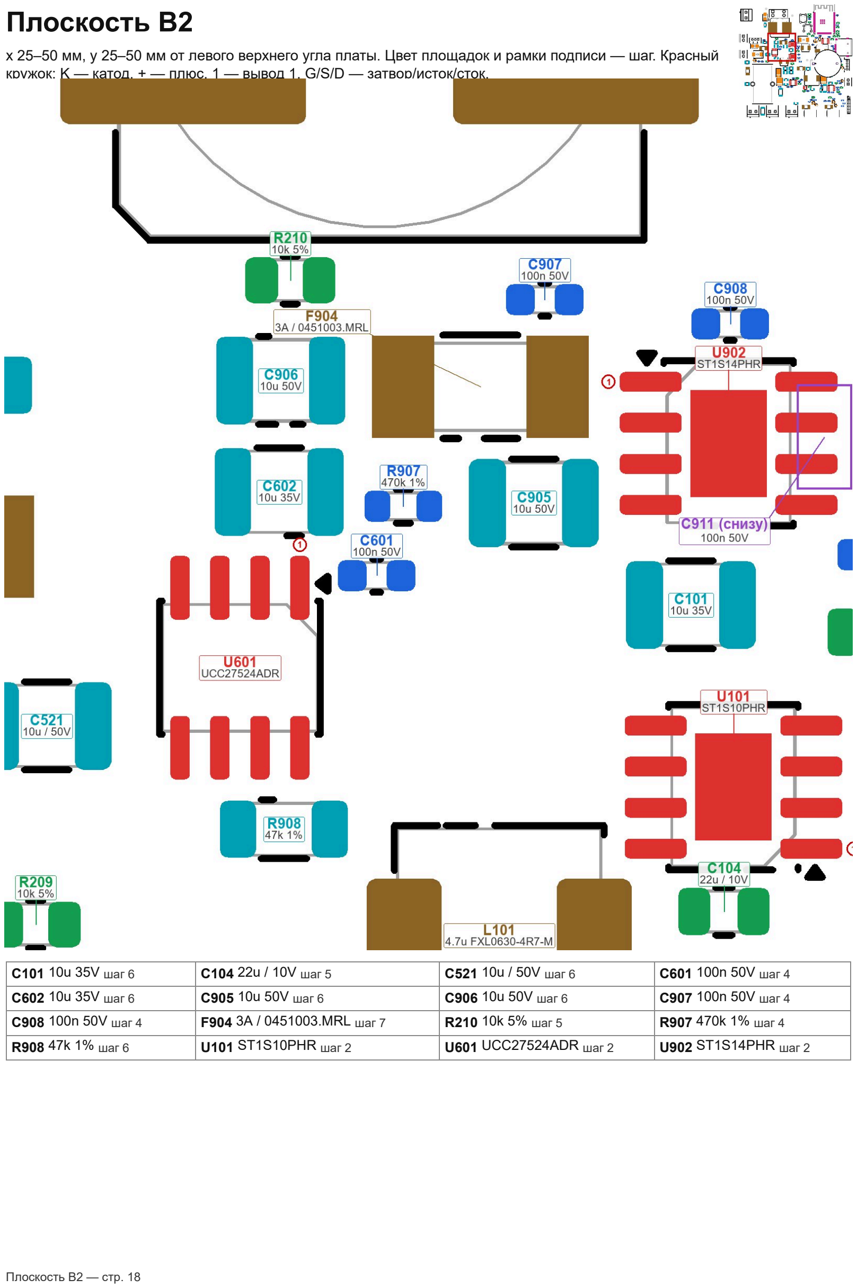
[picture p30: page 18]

x 25–50 мм, y 25–50 мм от левого верхнего угла платы. Цвет площадок и рамки подписи — шаг. Красный кружок: K — катод, + — плюс, 1 — вывод 1, G/S/D — затвор/исток/сток.

C101 10u 35V шаг 6 | C104 22u / 10V шаг 5 | C521 10u / 50V шаг 6 | C601 100n 50V шаг 4
C602 10u 35V шаг 6 | C905 10u 50V шаг 6 | C906 10u 50V шаг 6 | C907 100n 50V шаг 4
C908 100n 50V шаг 4 | F904 3A / 0451003.MRL шаг 7 | R210 10k 5% шаг 5 | R907 470k 1% шаг 4
R908 47k 1% шаг 6 | U101 ST1S10PHR шаг 2 | U601 UCC27524ADR шаг 2 | U902 ST1S14PHR шаг 2

Плоскость B2 — стр. 18

# Плоскость C2

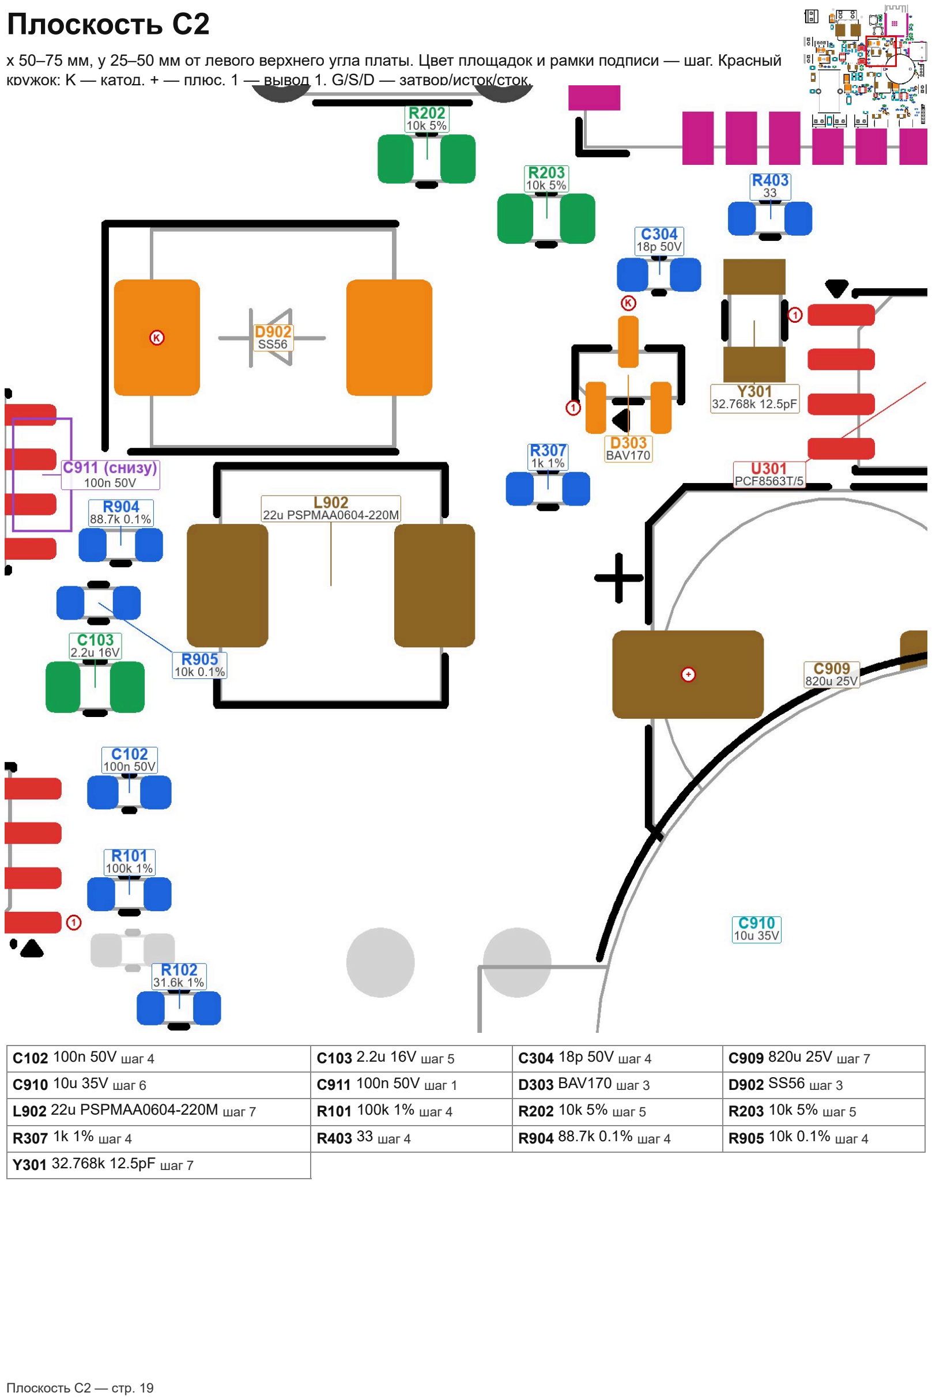
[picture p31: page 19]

x 50–75 мм, y 25–50 мм от левого верхнего угла платы. Цвет площадок и рамки подписи — шаг. Красный кружок: K — катод, + — плюс, 1 — вывод 1, G/S/D — затвор/исток/сток.

C102 100n 50V шаг 4 | C103 2.2u 16V шаг 5 | C304 18p 50V шаг 4 | C909 820u 25V шаг 7
C910 10u 35V шаг 6 | C911 100n 50V шаг 1 | D303 BAV170 шаг 3 | D902 SS56 шаг 3
L902 22u PSPMAA0604-220M шаг 7 | R101 100k 1% шаг 4 | R202 10k 5% шаг 5 | R203 10k 5% шаг 5
R307 1k 1% шаг 4 | R403 33 шаг 4 | R904 88.7k 0.1% шаг 4 | R905 10k 0.1% шаг 4
Y301 32.768k 12.5pF шаг 7

Плоскость C2 — стр. 19

# Плоскость D2

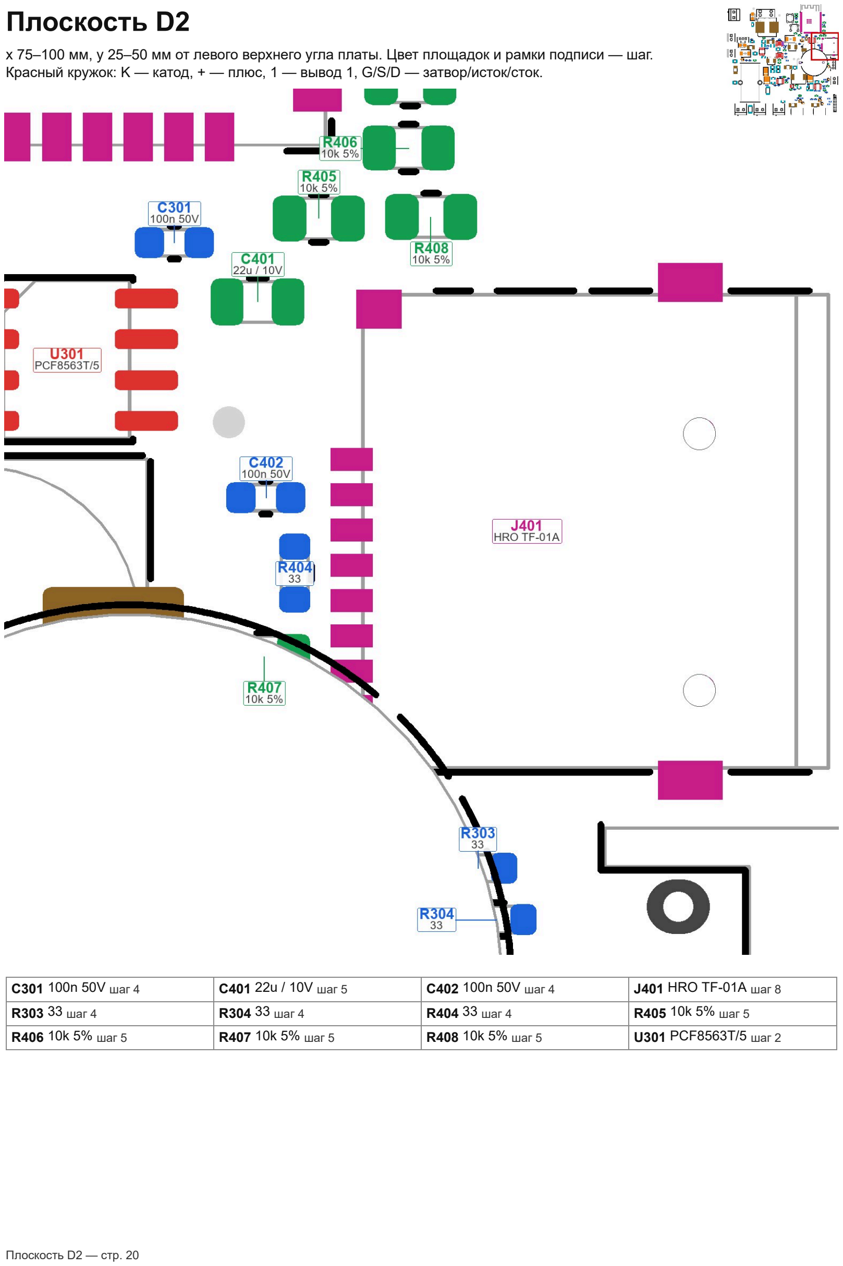
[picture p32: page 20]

x 75–100 мм, y 25–50 мм от левого верхнего угла платы. Цвет площадок и рамки подписи — шаг. Красный кружок: K — катод, + — плюс, 1 — вывод 1, G/S/D — затвор/исток/сток.

C301 100n 50V шаг 4 | C401 22u / 10V шаг 5 | C402 100n 50V шаг 4 | J401 HRO TF-01A шаг 8
R303 33 шаг 4 | R304 33 шаг 4 | R404 33 шаг 4 | R405 10k 5% шаг 5
R406 10k 5% шаг 5 | R407 10k 5% шаг 5 | R408 10k 5% шаг 5 | U301 PCF8563T/5 шаг 2

Плоскость D2 — стр. 20

# Плоскость A3

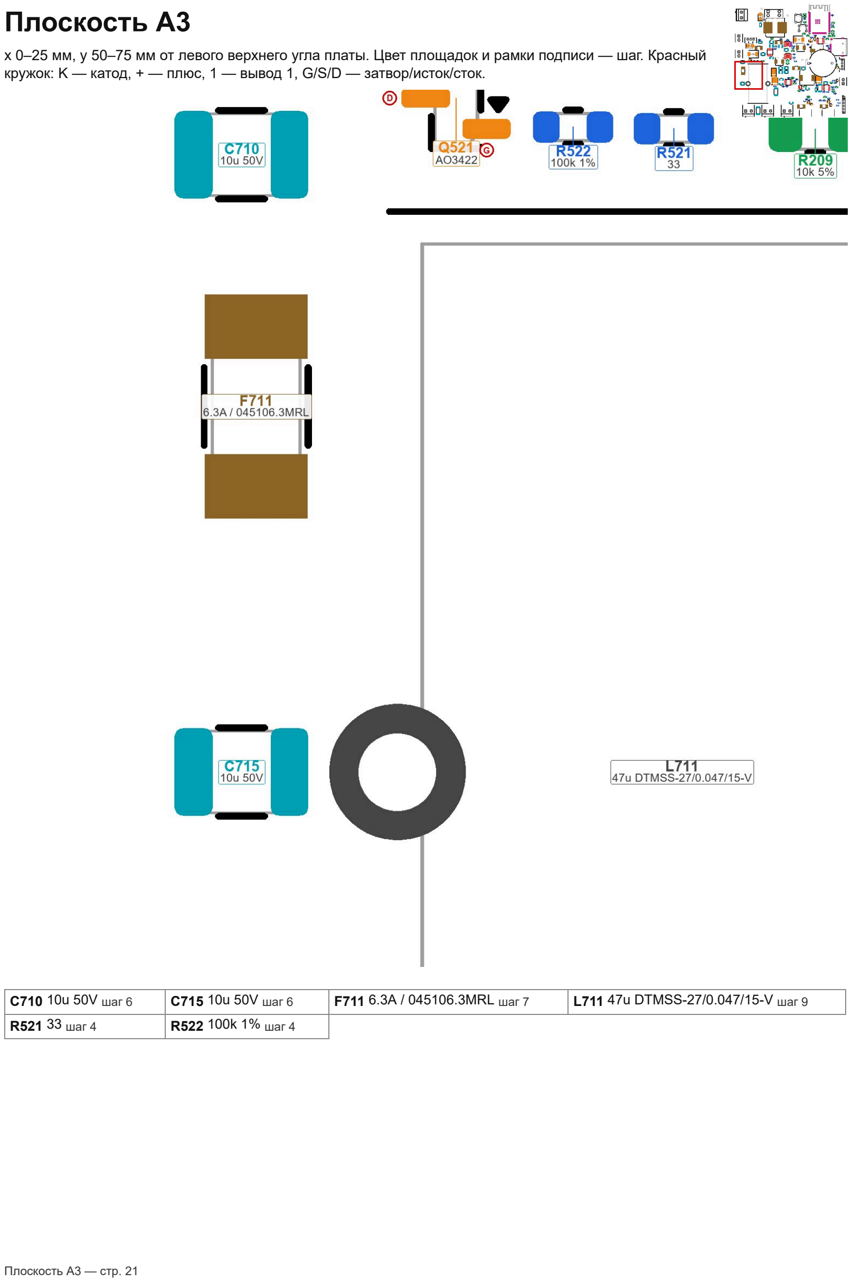
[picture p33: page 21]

x 0–25 мм, y 50–75 мм от левого верхнего угла платы. Цвет площадок и рамки подписи — шаг. Красный кружок: K — катод, + — плюс, 1 — вывод 1, G/S/D — затвор/исток/сток.

C710 10u 50V шаг 6 | C715 10u 50V шаг 6 | F711 6.3A / 045106.3MRL шаг 7 | L711 47u DTMSS-27/0.047/15-V шаг 9
R521 33 шаг 4 | R522 100k 1% шаг 4

Плоскость A3 — стр. 21

# Плоскость B3

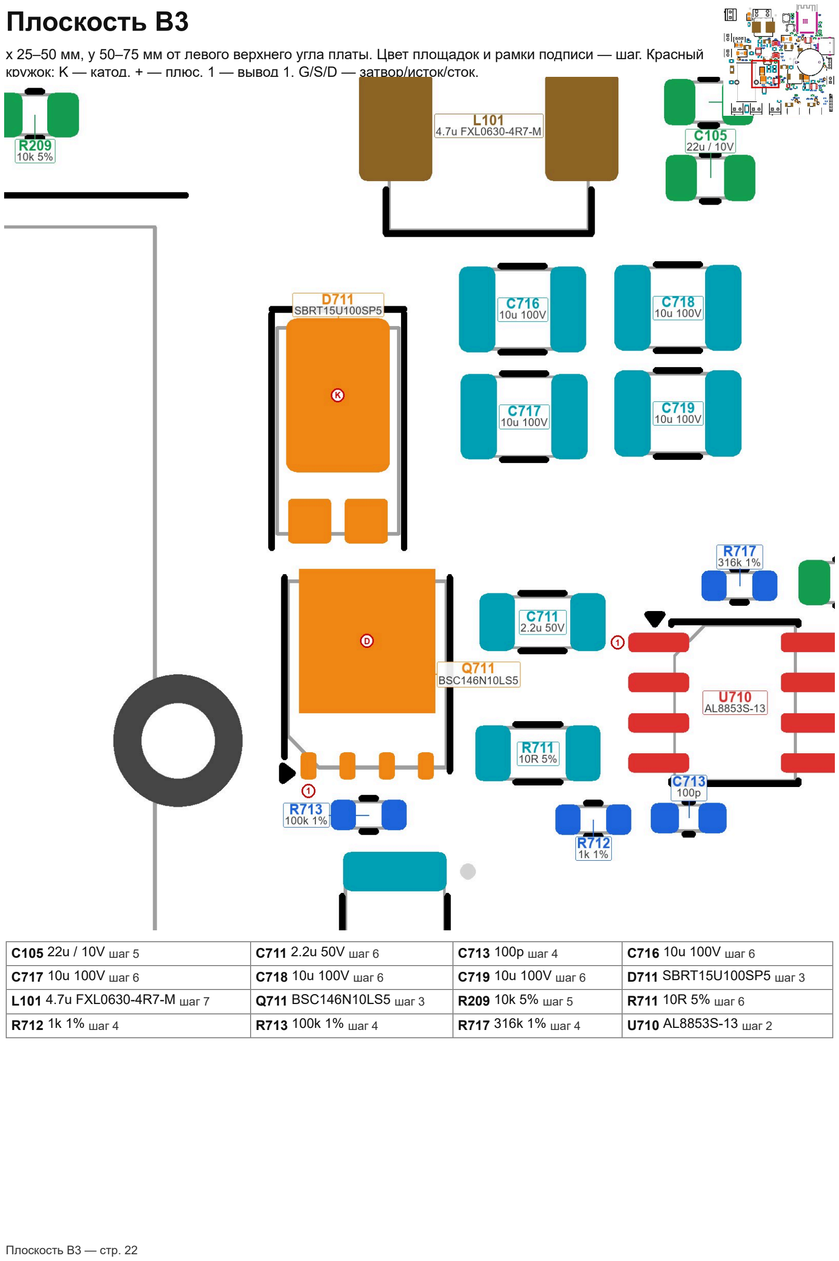
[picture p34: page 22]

x 25–50 мм, y 50–75 мм от левого верхнего угла платы. Цвет площадок и рамки подписи — шаг. Красный кружок: K — катод, + — плюс, 1 — вывод 1, G/S/D — затвор/исток/сток.

C105 22u / 10V шаг 5 | C711 2.2u 50V шаг 6 | C713 100p шаг 4 | C716 10u 100V шаг 6
C717 10u 100V шаг 6 | C718 10u 100V шаг 6 | C719 10u 100V шаг 6 | D711 SBRT15U100SP5 шаг 3
L101 4.7u FXL0630-4R7-M шаг 7 | Q711 BSC146N10LS5 шаг 3 | R209 10k 5% шаг 5 | R711 10R 5% шаг 6
R712 1k 1% шаг 4 | R713 100k 1% шаг 4 | R717 316k 1% шаг 4 | U710 AL8853S-13 шаг 2

Плоскость B3 — стр. 22

# Плоскость C3

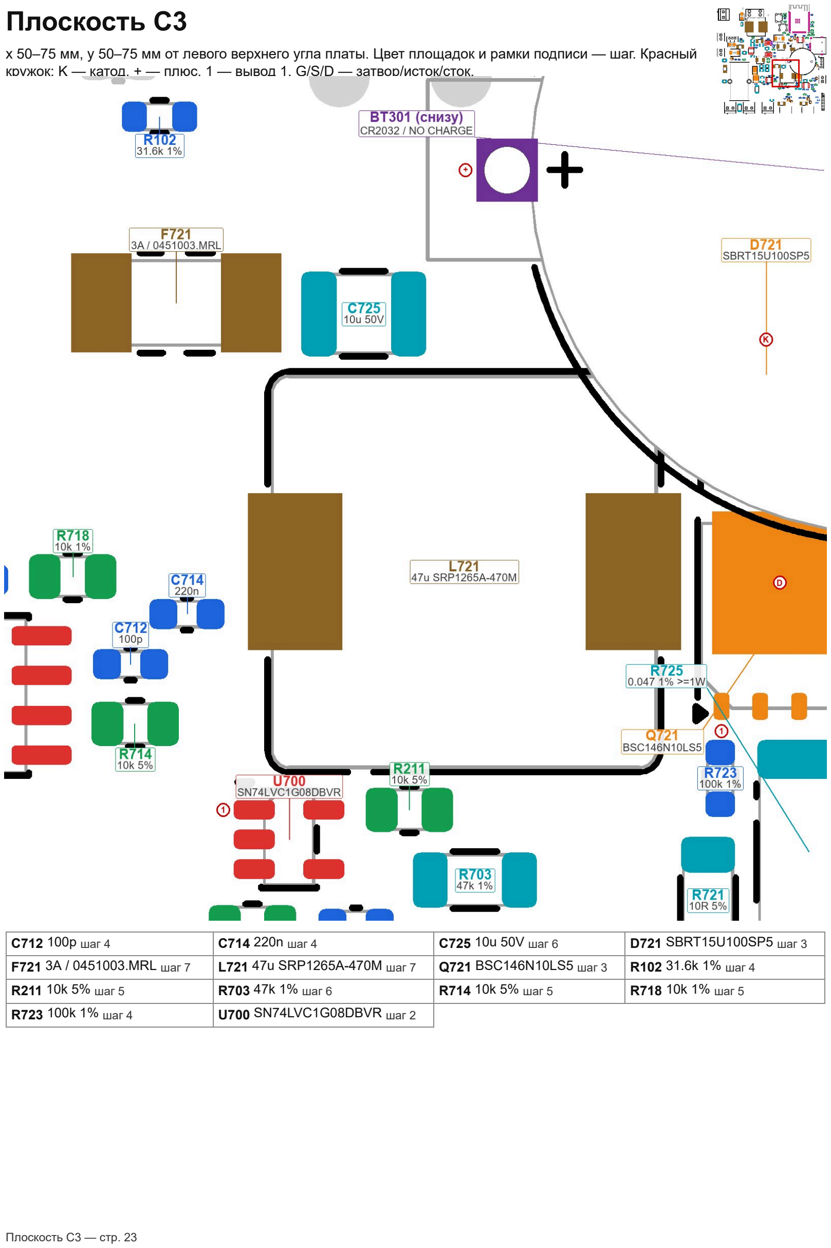
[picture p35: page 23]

x 50–75 мм, y 50–75 мм от левого верхнего угла платы. Цвет площадок и рамки подписи — шаг. Красный кружок: K — катод, + — плюс, 1 — вывод 1, G/S/D — затвор/исток/сток.

C712 100p шаг 4 | C714 220n шаг 4 | C725 10u 50V шаг 6 | D721 SBRT15U100SP5 шаг 3
F721 3A / 0451003.MRL шаг 7 | L721 47u SRP1265A-470M шаг 7 | Q721 BSC146N10LS5 шаг 3 | R102 31.6k 1% шаг 4
R211 10k 5% шаг 5 | R703 47k 1% шаг 6 | R714 10k 5% шаг 5 | R718 10k 1% шаг 5
R723 100k 1% шаг 4 | U700 SN74LVC1G08DBVR шаг 2

Плоскость C3 — стр. 23

# Плоскость D3

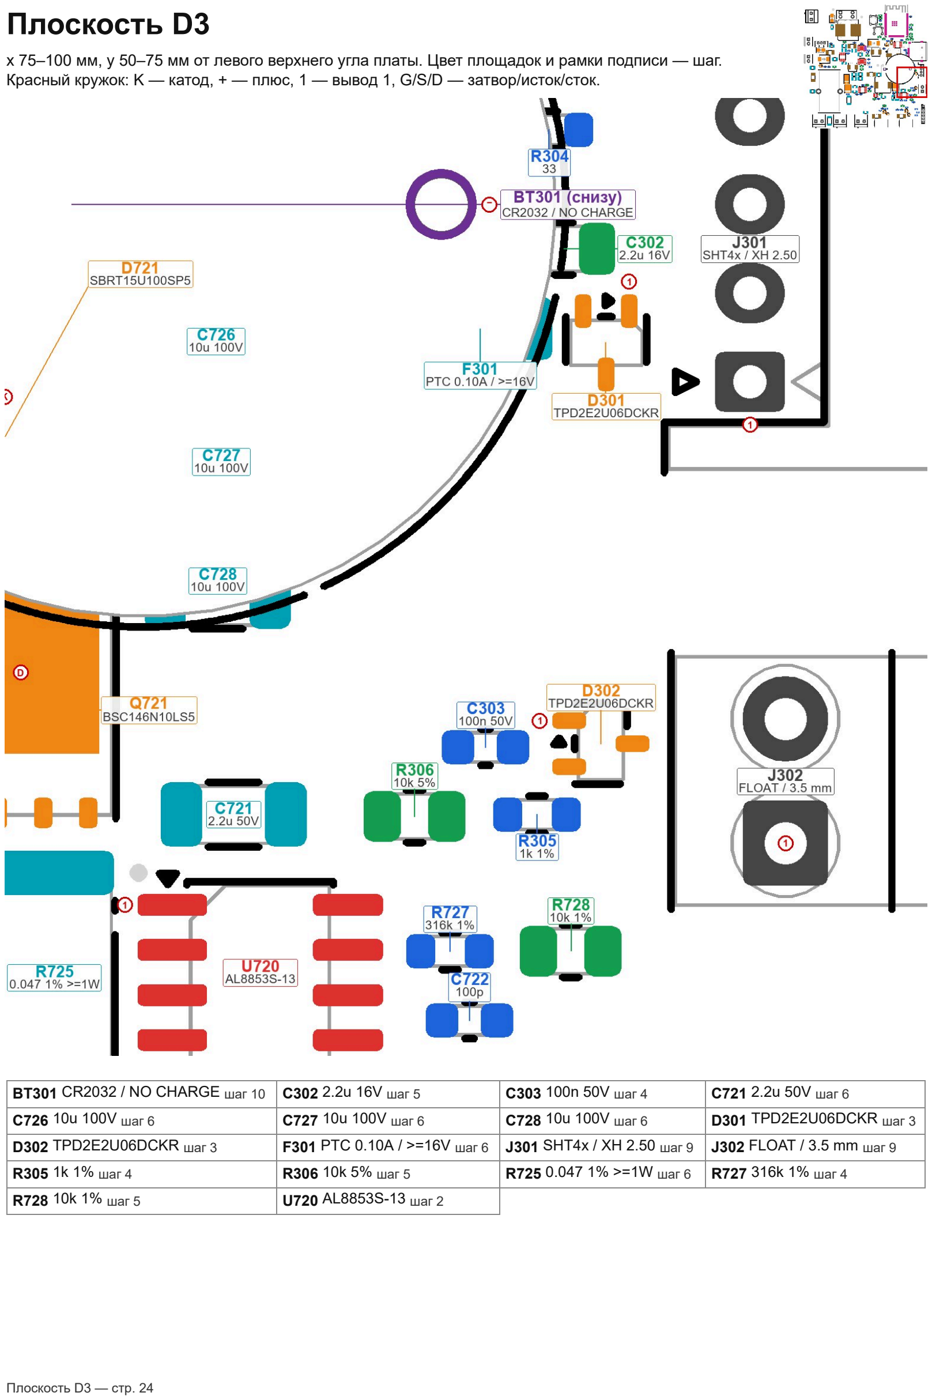
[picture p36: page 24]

x 75–100 мм, y 50–75 мм от левого верхнего угла платы. Цвет площадок и рамки подписи — шаг. Красный кружок: K — катод, + — плюс, 1 — вывод 1, G/S/D — затвор/исток/сток.

BT301 CR2032 / NO CHARGE шаг 10 | C302 2.2u 16V шаг 5 | C303 100n 50V шаг 4 | C721 2.2u 50V шаг 6
C726 10u 100V шаг 6 | C727 10u 100V шаг 6 | C728 10u 100V шаг 6 | D301 TPD2E2U06DCKR шаг 3
D302 TPD2E2U06DCKR шаг 3 | F301 PTC 0.10A / >=16V шаг 6 | J301 SHT4x / XH 2.50 шаг 9 | J302 FLOAT / 3.5 mm шаг 9
R305 1k 1% шаг 4 | R306 10k 5% шаг 5 | R725 0.047 1% >=1W шаг 6 | R727 316k 1% шаг 4
R728 10k 1% шаг 5 | U720 AL8853S-13 шаг 2

Плоскость D3 — стр. 24

# Плоскость A4

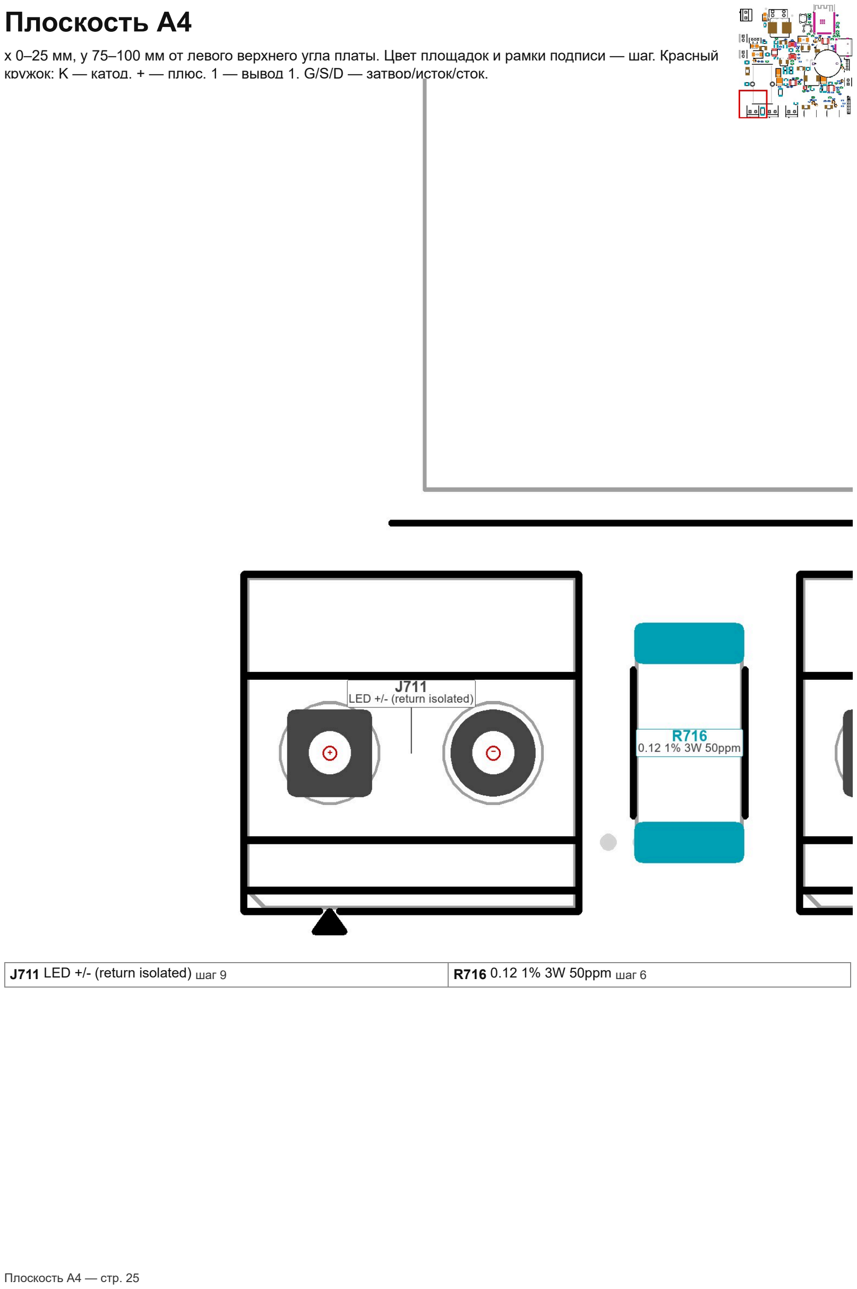
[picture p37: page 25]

x 0–25 мм, y 75–100 мм от левого верхнего угла платы. Цвет площадок и рамки подписи — шаг. Красный кружок: K — катод, + — плюс, 1 — вывод 1, G/S/D — затвор/исток/сток.

J711 LED +/ (return isolated) шаг 9 | R716 0.12 1% 3W 50ppm шаг 6

Плоскость A4 — стр. 25

# Плоскость B4

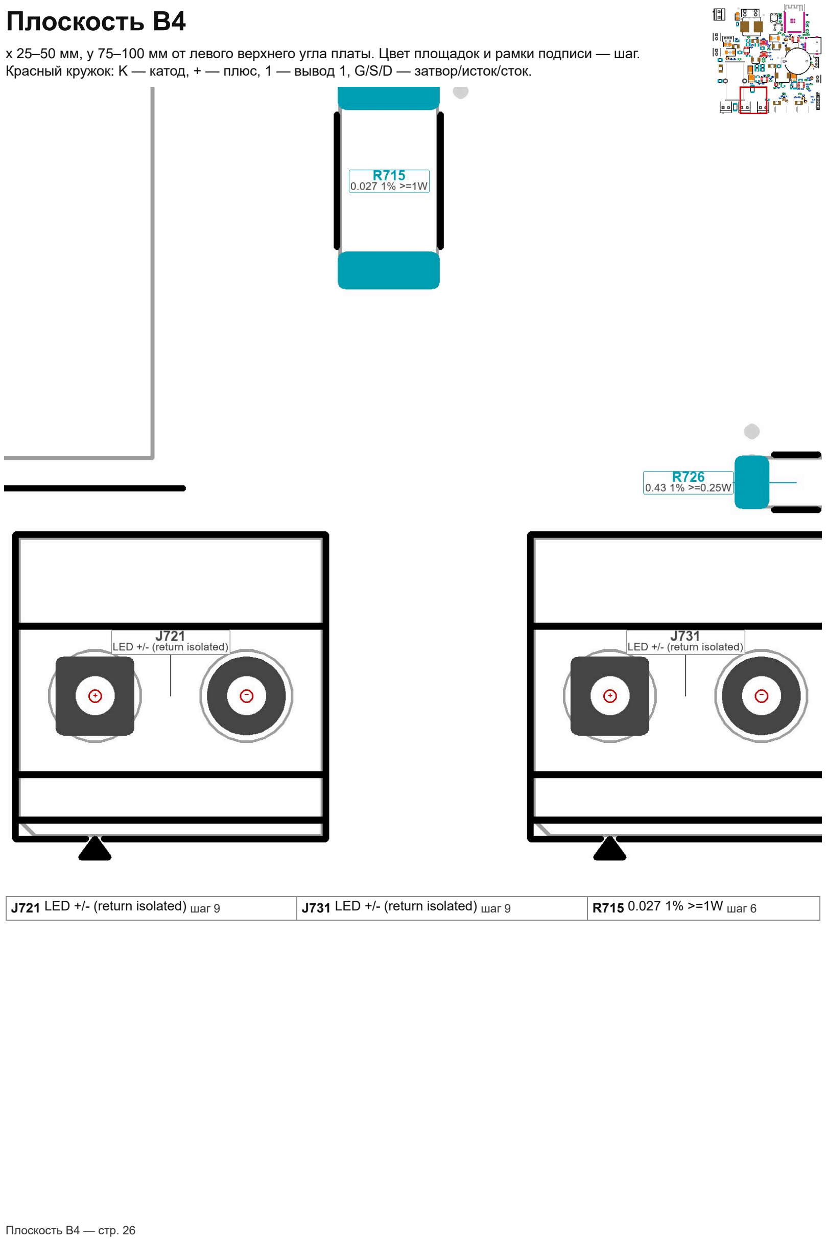
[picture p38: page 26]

x 25–50 мм, y 75–100 мм от левого верхнего угла платы. Цвет площадок и рамки подписи — шаг. Красный кружок: K — катод, + — плюс, 1 — вывод 1, G/S/D — затвор/исток/сток.

J721 LED +/ (return isolated) шаг 9 | J731 LED +/ (return isolated) шаг 9 | R715 0.027 1% >=1W шаг 6

Плоскость B4 — стр. 26

# Плоскость C4

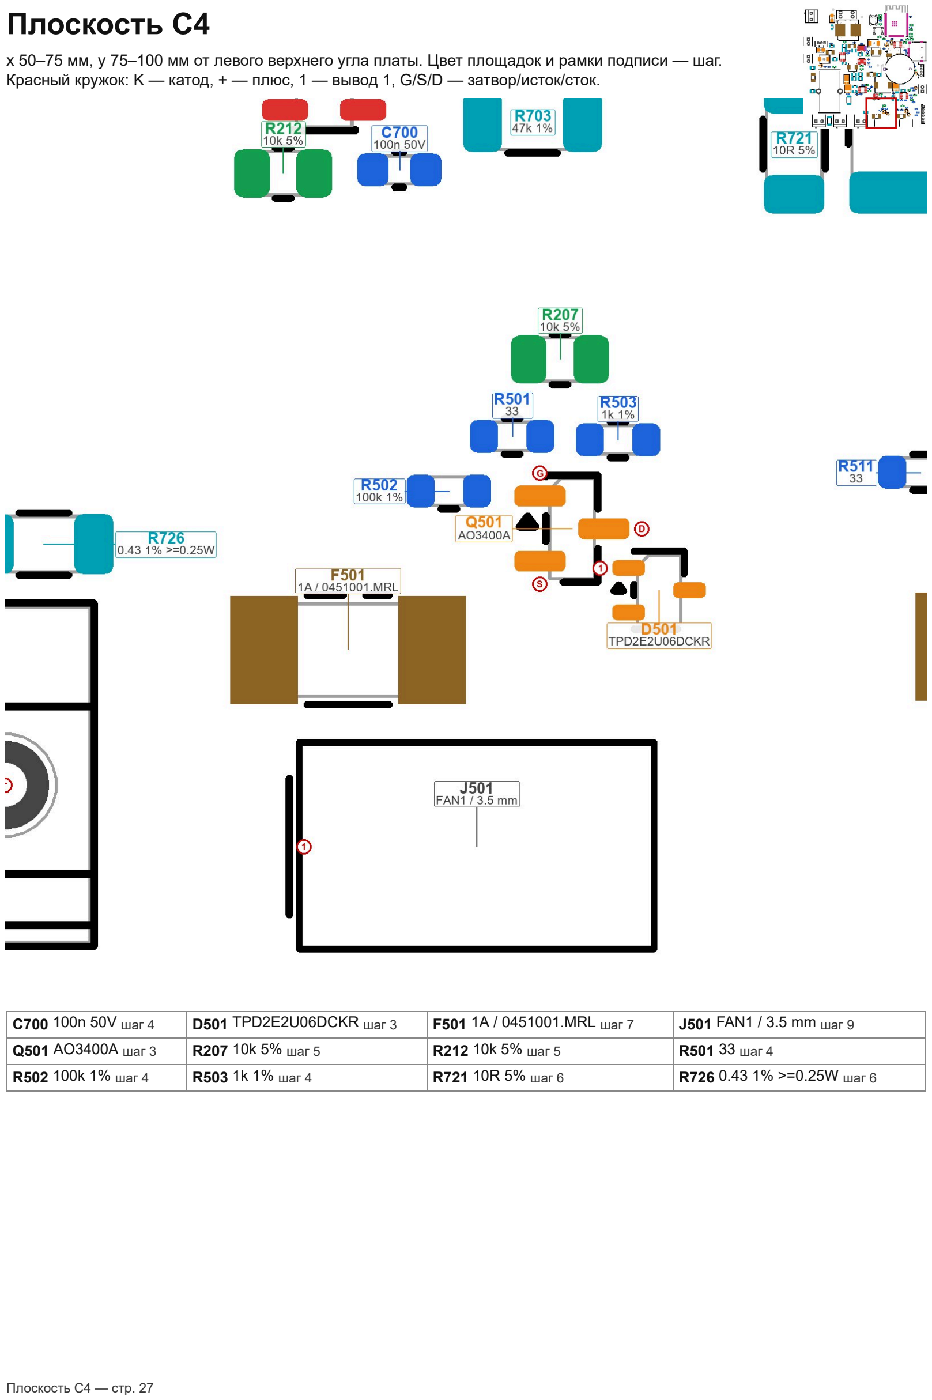
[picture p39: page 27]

x 50–75 мм, y 75–100 мм от левого верхнего угла платы. Цвет площадок и рамки подписи — шаг. Красный кружок: K — катод, + — плюс, 1 — вывод 1, G/S/D — затвор/исток/сток.

C700 100n 50V шаг 4 | D501 TPD2E2U06DCKR шаг 3 | F501 1A / 0451001.MRL шаг 7 | J501 FAN1 / 3.5 mm шаг 9
Q501 AO3400A шаг 3 | R207 10k 5% шаг 5 | R212 10k 5% шаг 5 | R501 33 шаг 4
R502 100k 1% шаг 4 | R503 1k 1% шаг 4 | R721 10R 5% шаг 6 | R726 0.43 1% >=0.25W шаг 6

Плоскость C4 — стр. 27

# Плоскость D4

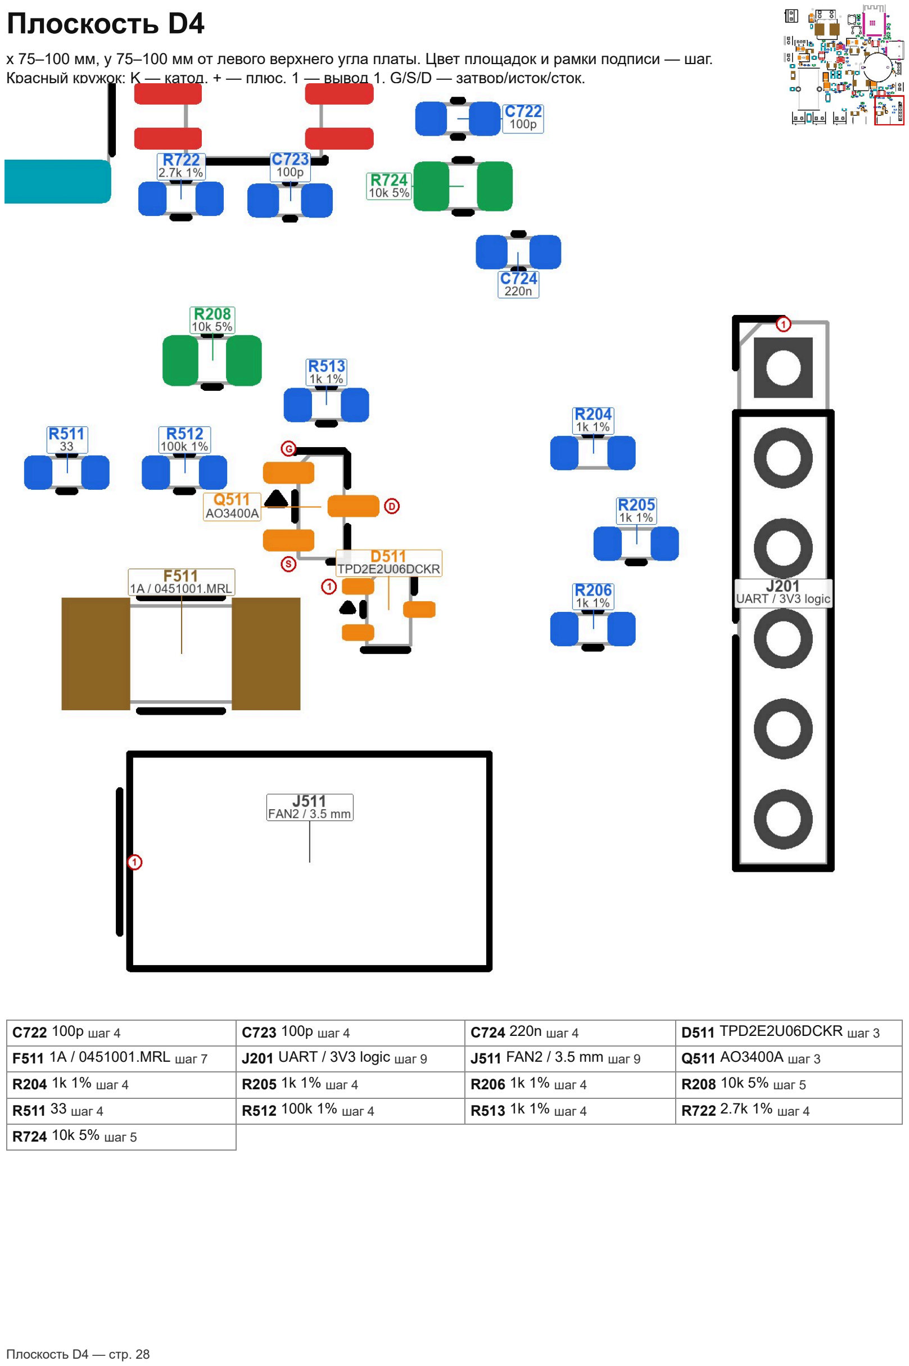
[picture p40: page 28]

x 75–100 мм, y 75–100 мм от левого верхнего угла платы. Цвет площадок и рамки подписи — шаг. Красный кружок: K — катод, + — плюс, 1 — вывод 1, G/S/D — затвор/исток/сток.

C722 100p шаг 4 | C723 100p шаг 4 | C724 220n шаг 4 | D511 TPD2E2U06DCKR шаг 3
F511 1A / 0451001.MRL шаг 7 | J201 UART / 3V3 logic шаг 9 | J511 FAN2 / 3.5 mm шаг 9 | Q511 AO3400A шаг 3
R204 1k 1% шаг 4 | R205 1k 1% шаг 4 | R206 1k 1% шаг 4 | R208 10k 5% шаг 5
R511 33 шаг 4 | R512 100k 1% шаг 4 | R513 1k 1% шаг 4 | R722 2.7k 1% шаг 4
R724 10k 5% шаг 5

Плоскость D4 — стр. 28

# Полярность и ориентация

Электролиты SMD — C901 C909
Плюсовая площадка 1 отмечена красным «+». C901 — +24V, C909 — +12V; вторая площадка — земля. На корпусе минус обозначен полосой. Неправильная полярность выводит конденсатор из строя.

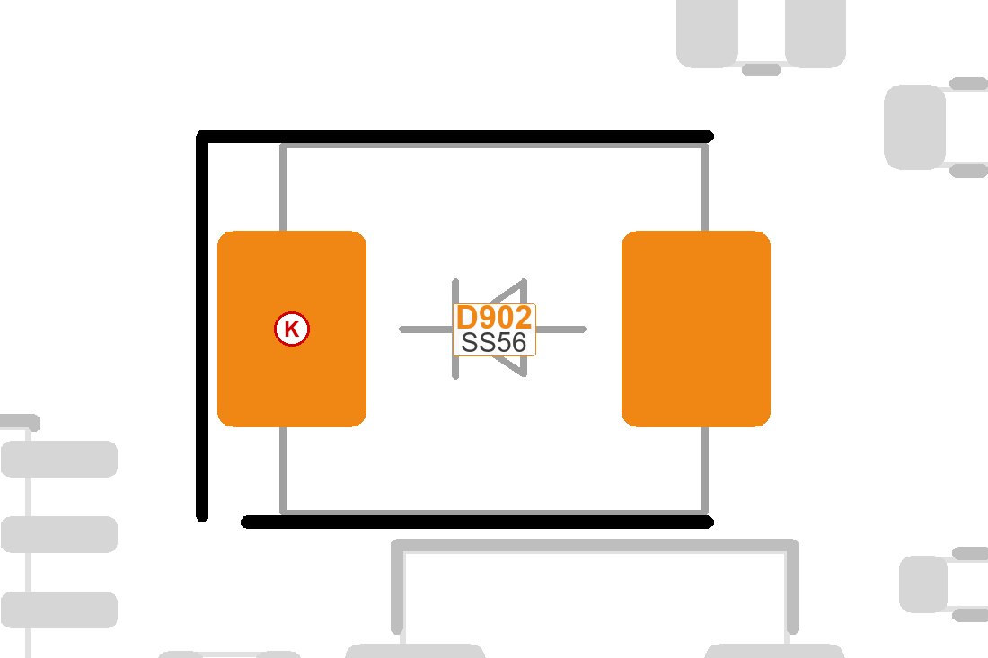
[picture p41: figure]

Диоды Шоттки SS56 (SMC) — D521 D902
Катод — вывод с полосой на корпусе; на плате это площадка 1 (красное «K»): D521 — к цепи PUMP_24V, D902 — к BUCK12_SW. Анод — площадка 2.

Диоды SBRT15U100SP5 (PowerDI5) — D711 D721
Катод — широкий выводтеплоотвод (красное «K» на большой площадке, цепь LED1_OUT / LED2_OUT). Два узких вывода с другой стороны — анод (SW). Широкая площадка корпуса должна лечь на большую площадку платы.

Двунаправленные диоды SMBJ26CA — D601 D901 Полярности нет — ставить любой стороной. Маркировочная полоса на таком диоде отсутствует или не имеет значения.

Диод BAV170 (SOT-23) — D303
Сдвоенный диод с общим катодом: вывод 3 — общий катод (красное «K», цепь RTC_VDD), выводы 1 и 2 — аноды (+3V3 и батарея через резистор).

Защита TPD2E2U06DCKR (SC-70) — D301 D302 D501 D511 Ориентация по выводу 1 (красное «1», точка или скос на корпусе). Вывод 3 — земля.

Полярность и ориентация — стр. 29

# Полярность и ориентация

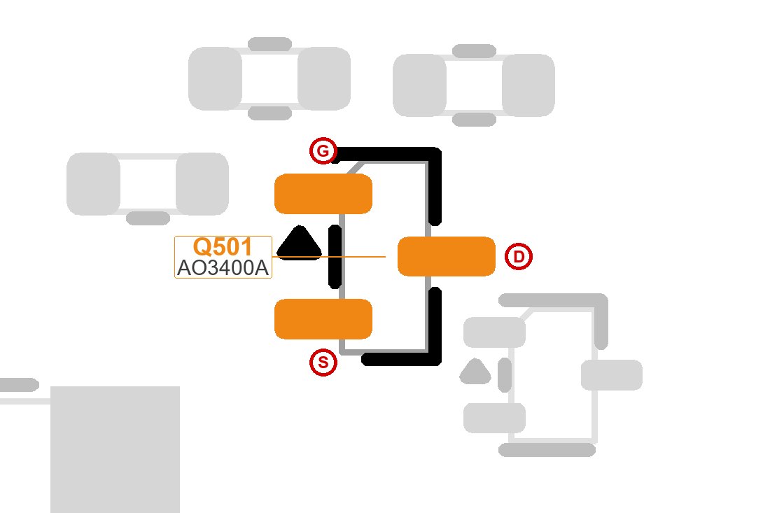
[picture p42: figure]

Транзисторы SOT-23 (AO3400A, AO3422) — Q501 Q511 Q521
Выводы: 1 — затвор (G), 2 — исток (S), 3 — сток (D). Вывод 3 один на своей стороне корпуса, выводы 1 и 2 — на другой.

BSC146N10LS5 (TDSON-8) — Q711 Q721
Вывод 1 (красное «1») — точка на корпусе, исток. Выводы 1– 3 исток, 4 затвор, 5–8 и большая площадка (красное «D») — сток. Припаять феном с пастой или прогреть большую площадку.

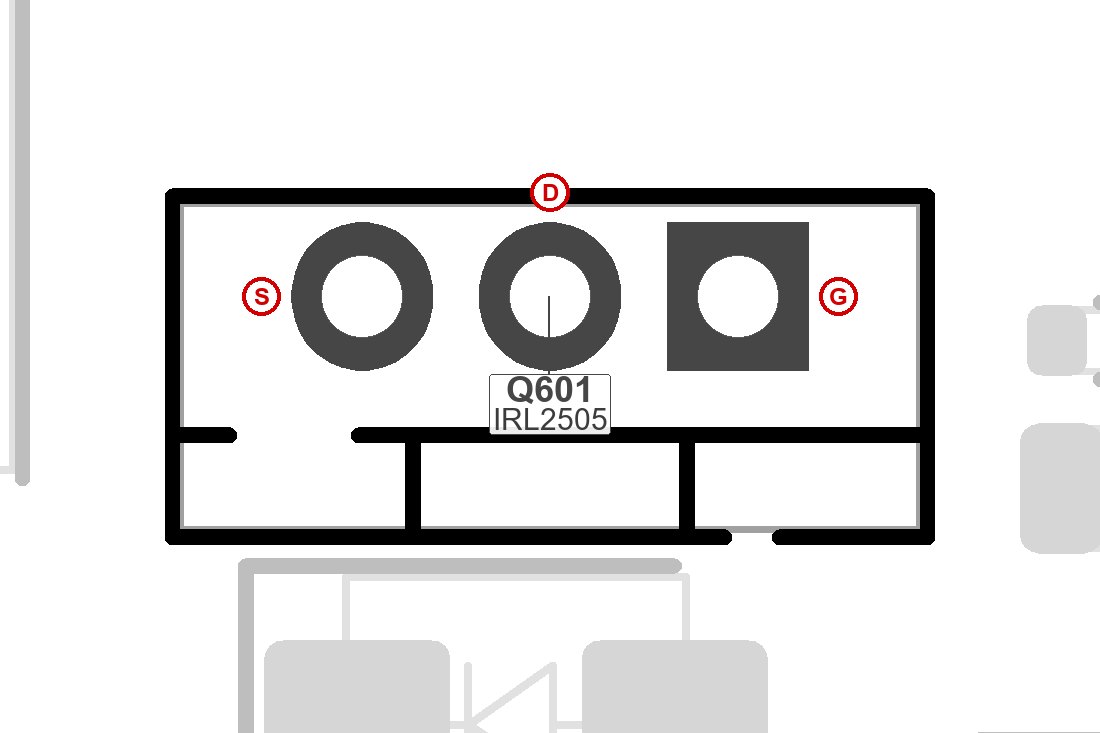
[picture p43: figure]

IRL2505 (TO-220, стоя) — Q601
Три ножки по порядку на плате: 1 — затвор (G, квадратная площадка), 2 — сток (D), 3 — исток (S). Лицевая сторона корпуса (с надписью) смотрит к верху рисунка, металлическая пластина — к нижней стороне, где контур корпуса выступает дальше от ножек. Радиатор не нужен: при 4,2 А рассеивается около 0,14 Вт.

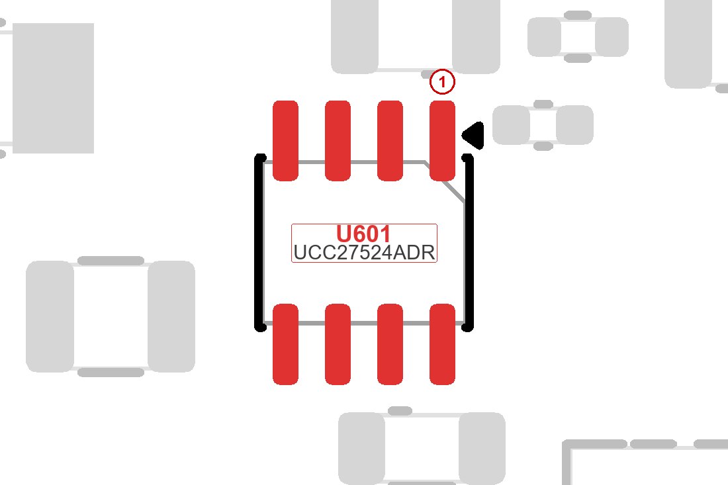
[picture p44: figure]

SOIC-8: U301, U601, U710, U720 — U301 U601 U710 U720 Вывод 1 — красное «1»; на корпусе — точка или скос возле вывода 1. Остальные выводы — против часовой стрелки при взгляде сверху. SOIC-8 с площадкой EP: U101, U902 — U101 U902

Вывод 1 — красное «1». Площадка EP под корпусом (земля) припаивается феном.

SOT-23-5: U700 — U700
Вывод 1 — красное «1» (точка на корпусе); на противоположной стороне два вывода (4, 5), на этой три (1, 2, 3). Полярность и ориентация — стр. 30

# Полярность и ориентация

Модуль ESP32-WROOM-32E: U201 — U201
Вывод 1 (GND) — красное «1», угол модуля у левого края; антенна (печатный зигзаг) — к верхнему краю платы, над ней нет меди и деталей. Под модулем площадка земли: прогреть феном.

Клеммники питания — J901
J901 — вход 24 В: отмечены «+» (+24V) и «−» (GND), провод входит со стороны левого края платы.
Вывод | Назначение | Цепь
1 | − | GND
2 | + | +24V

Клеммники 3,5 мм: PTC, насос, поплавок — J601 J521 J302 J601 — нагреватель: «+» = +24V_LOADS, «−» = коммутируемый минус. J521 — помпа 24 В: «+» = PUMP_24V, «−» = сток ключа. J302 — датчик уровня (поплавок): вывод 1 сигнал, вывод 2 земля. Провод входит со стороны ближайшего края.

Вывод | Назначение | Цепь
1 | + | +24V_LOADS
2 | − | HEATER_DRAIN

Клеммники LED: J711, J721, J731 — J711 J721 J731 Плюс светильника — вывод 1 (LEDx_OUT), минус — вывод 2 (LEDx_RETURN). J721 и J731 — две ветви канала CH2 (+ у них общий). Провод входит снизу.

Вывод | Назначение | Цепь
1 | + | LED1_OUT
2 | − | LED1_RETURN

Полярность и ориентация — стр. 31

# Полярность и ориентация

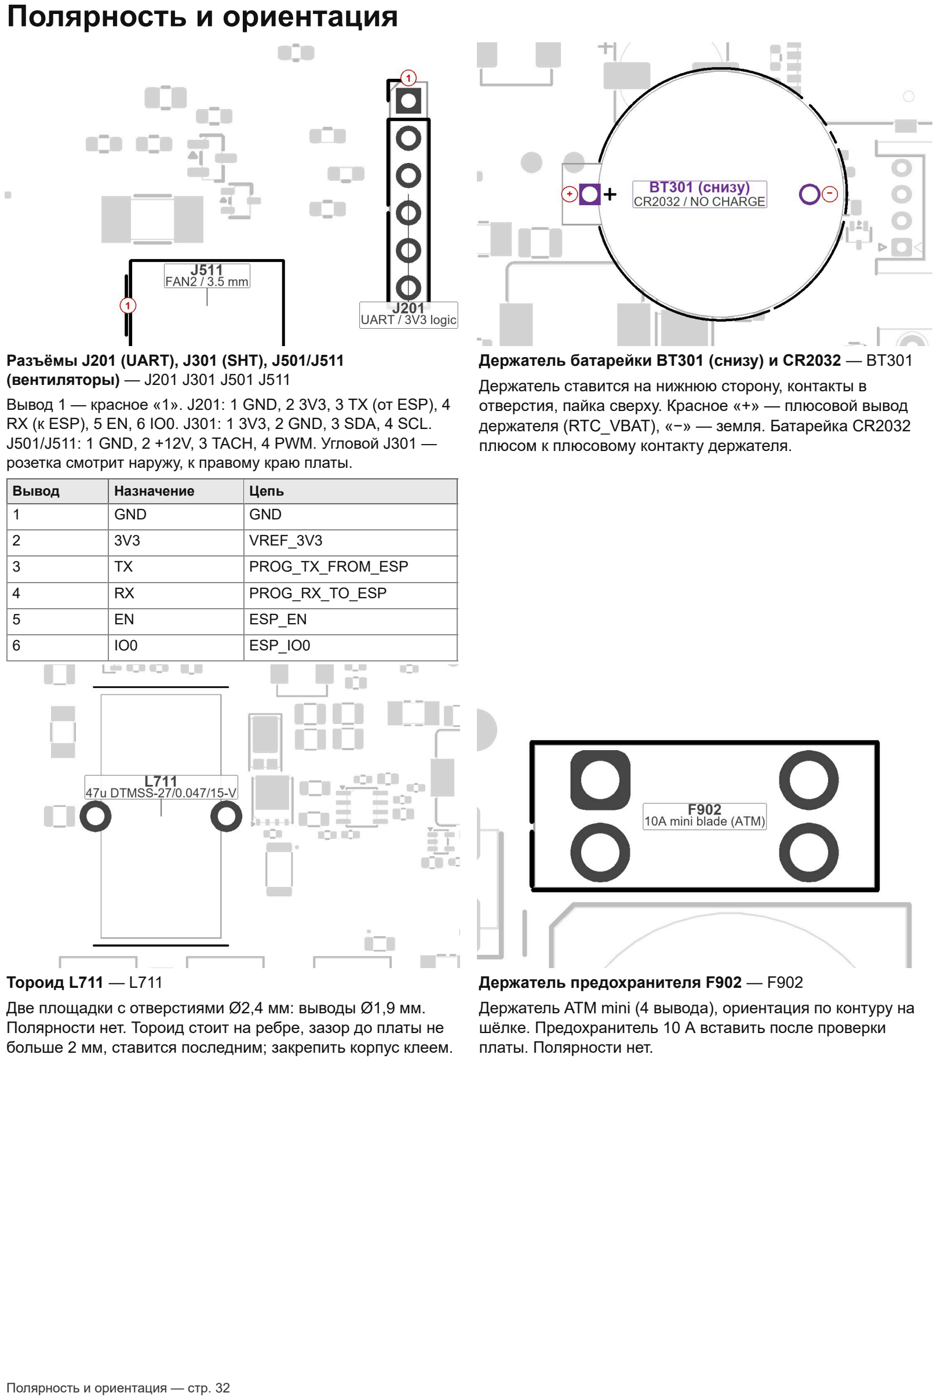
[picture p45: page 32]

Разъёмы J201 (UART), J301 (SHT), J501/J511 (вентиляторы) — J201 J301 J501 J511
Вывод 1 — красное «1». J201: 1 GND, 2 3V3, 3 TX (от ESP), 4 RX (к ESP), 5 EN, 6 IO0. J301: 1 3V3, 2 GND, 3 SDA, 4 SCL. J501/J511: 1 GND, 2 +12V, 3 TACH, 4 PWM. Угловой J301 — розетка смотрит наружу, к правому краю платы.
Вывод | Назначение | Цепь
1 | GND | GND
2 | 3V3 | VREF_3V3
3 | TX | PROG_TX_FROM_ESP
4 | RX | PROG_RX_TO_ESP
5 | EN | ESP_EN
6 | IO0 | ESP_IO0

Держатель батарейки BT301 (снизу) и CR2032 — BT301 Держатель ставится на нижнюю сторону, контакты в отверстия, пайка сверху. Красное «+» — плюсовой вывод держателя (RTC_VBAT), «−» — земля. Батарейка CR2032 плюсом к плюсовому контакту держателя.

Тороид L711 — L711
Две площадки с отверстиями Ø2,4 мм: выводы Ø1,9 мм. Полярности нет. Тороид стоит на ребре, зазор до платы не больше 2 мм, ставится последним; закрепить корпус клеем.

Держатель предохранителя F902 — F902
Держатель ATM mini (4 вывода), ориентация по контуру на шёлке. Предохранитель 10 А вставить после проверки
платы. Полярности нет. Полярность и ориентация — стр. 32

# Полярность и ориентация

Кнопки SW201 (RESET) и SW202 (BOOT) — SW201 SW202 Кнопки 6×6×10: выводы входят в отверстия только в одном положении (прямоугольный шаблон). Полярности нет; не путать надписи RESET и BOOT.

Без полярности — Y301
Кварц Y301 (32,768 кГц, SMD 3215): выводы равноправны. Так же ставятся все резисторы, керамические конденсаторы, индуктивности L101, L902, L721 и предохранители. Полярность и ориентация — стр. 33

# Контроль после сборки

№ Проверка
1 | Осмотр под увеличением: перемычки между выводами U201, U902, U101, U601, U710, U720, U301, J401, непропаянные выводы SMD и выводных деталей.
2 | Полярность по странице «Главное»: C901, C909, D521, D902, D711, D721, D303, все микросхемы, Q601, клеммники, BT301.
3 | Значения: три разных 10 мкФ в корпусе 1210, L101/L902, шунты 2512 (R715 0,027; R716 0,12; R725 0,047), предохранители Littelfuse.
4 | Мультиметр без питания: нет короткого замыкания +24V, +12V, +3V3 на GND; нагрузки (светильники, PTC, помпа, вентиляторы) не подключены.
5 | Предохранитель 10 А в F902 и батарейку CR2032 вставить после проверки платы.
6 | Первое включение — лабораторным блоком 24 В с ограничением тока 0,3 А, измерения по review/Bench_checklist_cheap1.md (напряжение +12V и +3V3, пульсации, выбросы на SW).

Если чтото нагревается без нагрузки или ток при 24 В выше ожидаемого — выключить и искать ошибку установки (полярность, перемычка, не тот номинал).

Контроль после сборки — стр. 34

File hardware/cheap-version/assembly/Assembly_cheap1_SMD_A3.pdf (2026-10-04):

# GrowBox cheap-1 — схема установки SMD-деталей (вид сверху, лист A3)

142 SMD-деталей, из них 141 сверху и C911 снизу. Таблица позиций и MPN — в Assembly_cheap1_A4.pdf, страница 2. Зелёные детали — без полярности, оранжевые — с полярностью; красный кружок — вывод, к которому должна встать метка на детали. Номинал стоит рядом с позицией; если для него не нашлось места, он есть в таблице. Нижняя сторона (плата перевёрнута, зеркально): C911

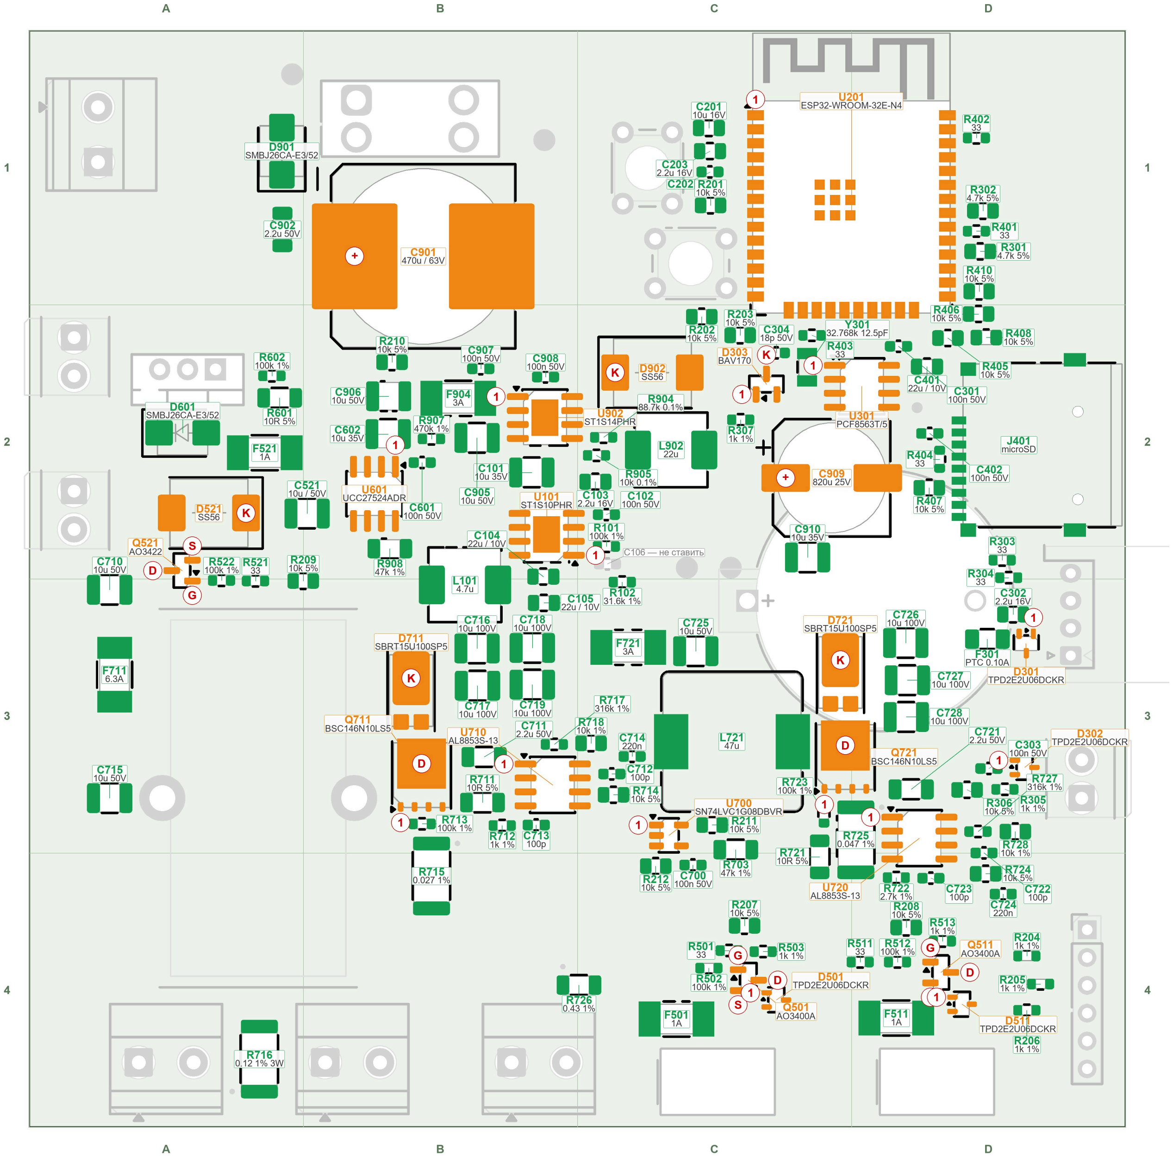
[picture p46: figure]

### Метки полярности на схеме

K катод диода — полоса на корпусе
+ / − | плюс / минус
1 вывод 1: точка, скос или метка на корпусе | микросхемы

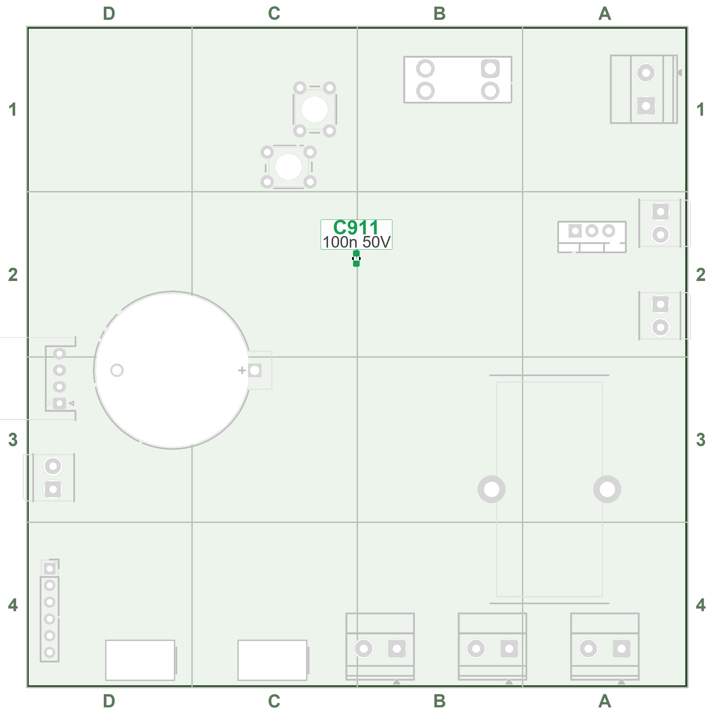
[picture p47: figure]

G S D | затвор, исток, сток

Серые детали — не из этой схемы (контекст). Сетка A–D, 1–4 — зоны 25 × 25 мм, как в столбце «Зоны» таблицы.

### Цвет детали

без полярности: резисторы, керамика, индуктивности, предохранители, кварц, SMBJ (D601, D901), microSD
с полярностью или выводом 1: диоды, электролиты, транзисторы, микросхемы, ESP32 — по красной метке

### Порядок пайки (колонка «Шаг»)

1 — C911 снизу; 2 — микросхемы; 3 — транзисторы и диоды; 4 — 0603; 5 — 0805; 6 — 1206, 1210, 2512, F301; 7 — индуктивности, предохранители Littelfuse, кварц, C901 и C909; 8 — ESP32 и microSD.

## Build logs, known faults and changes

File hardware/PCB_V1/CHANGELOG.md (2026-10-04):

# PCB_V1 — журнал ревизий

Кратко, от новых к старым. Подробности текущей схемы — [DESIGN.md](DESIGN.md). Отчёты и документы прежних ревизий убраны из рабочего дерева; ссылки на них — в разделе [«Архив»](#архив).

| Ревизия | Дата | Коммит | Что изменилось |
|---|---|---|---|
| **0.22, корпус** | 02.10.2026 | ветка `pcb-enclosure` | Печатный корпус `hardware/enclosure/`: основание и крышка, настенные уши, вентиляция, защёлки без винтов, окна под разъёмы по STEP платы, доступ к J301/J201 и BOOT/RESET через потолок. Генератор CadQuery, STEP/STL, проверка по STEP платы (пересечений нет, минимальный зазор 0,65 мм), рендеры. Плата и схема не менялись; корпус не печатался. |
| **0.22, документация** | 01.10.2026 | ветка `pcb-docs-simplify` | Сокращены README и повторная история замен; DESIGN описывает текущую схему, ROUTING_PREP — расчётные ограничения. Обновлён статус после DFM и BOM, сохранены открытые вопросы по меди и механике. Схема, плата и производственные файлы не менялись. |
| **0.22, BOM для LCSC** | 01.10.2026 | ветка `pcb-bom` | Заказной BOM: `export_lcsc_bom.py` собирает из схемы и снимка цен файл для загрузки на lcsc.com/bom (`BOM_LCSC_v22.csv`/`.xlsx`: 66 позиций, количество на одну плату) и полный BOM с минимальными партиями LCSC и ценами для 1 и 5 плат ($59,92 и $148,58); `check_all.py` следит за их актуальностью. Схема и плата не менялись. XT60PW-M (нет на LCSC) и CR2032 — отдельно. [BOM.md](BOM.md) |
| **0.22, замечания JLCDFM** | 01.10.2026 | ветка `pcb-dfm-fixes` | Анализатор JLCPCB (JLCDFM, отчёт пользователя) нашёл по первому архиву: шёлк у площадок (27 опасных) и на отверстиях (52), переходное в 0,07 мм от площадки, отверстие маски в 0,05 мм от дорожки, выводная площадка в 0,41 мм от SMD, ширина шёлка на минимуме. В плате: удалено 1 и переделано 3 переходных GND, исправлено 4 угла дорожек, F301 сдвинут на 0,1 мм, шёлк 0,2 мм и обрезан на 0,15 мм от площадок и отверстий (7 надписей сдвинуты); `lib_footprint_mismatch` в DRC — ignore. `check_fab.py` проверяет и эти категории, архив пересобран. DRC 0/0. [FAB.md](FAB.md) |
| **0.22, файлы для производства** | 01.10.2026 | ветка `pcb-fab` | Gerber и сверловка для JLCPCB (`fab/PCB_V1_v22_jlcpcb.zip`, 12 файлов, экспорт воспроизводим) и проверка платы по нормам JLCPCB (`check_fab.py`, 0 FAIL, 2 предупреждения). В плате изменена только ширина 494 линий шёлкографии: 0,12 → 0,15 мм. DRC 0/0. [FAB.md](FAB.md) |
| **0.22, разводка** | 01.10.2026 | ветка `pcb-routing` | Первая полная разводка без изменения схемы и размещения: DRC 0 нарушений и 0 несоединённых, In1 — сплошная GND (дорожек нет), GND и +3V3 заливки, силовые полигоны +24V на F.Cu и B.Cu, 909 дорожек, 292 переходных. Силовая часть — скриптом (`route_power.py`), сигналы — Freerouting 2.4.1 (`route_signals.py`), остаток — собственным лабиринтным роутером (`route_complete.py`); проверка `verify_routing.py`. Слив нагревателя 3,1 мм при расчётных 3,02 мм — единственный тонкий узел. [ROUTING.md](ROUTING.md) |
| **0.22** | 30.09.2026 | ветка `pcb-prerouting` | Подготовка к трассировке. Стек подтверждён: 1,6 мм, 1 oz снаружи, 0,5 oz внутри. Выходные MLCC LED → Murata GRM32EC72A106KE05L (X7S); microSD → HRO TF-01A на новом footprint `GrowBox:microSD_HRO_TF-01A`. TP301 на CLKOUT RTC (прошивка: `RTC_CLKOUT_TRIM`); net-tie NT711/NT712/NT721/NT722 для Kelvin-отводов CS/FB. Скрипт `analyze_copper.py`. 170 компонентов (4 net-tie без покупки), $30,04 на плату. [ROUTING_PREP.md](ROUTING_PREP.md) |
| 0.21 | 30.09.2026 | ветка `pcb-rtc-backup` | D303 BAT54C → JSCJ BAV170 (C68970), та же площадка SOT-23 и нумерация A1/A2/K3. Проверка питания RTC с учётом падения диода и R307. Связи и позиции всех 165 деталей прежние. Обновлены отчёты, цены и изображения; $31,63 на плату. [RTC_BACKUP_021.md](https://github.com/nikolajevs/ai/blob/1887d866ac820a41e9d1717056d188d7af6e6b51/pcb/PCB_V1/RTC_BACKUP_021.md) |
| 0.20 | 30.09.2026 | ветка `pcb-rev020` | Удешевление со сменой платы и прошивки: RTC DS3231MZ → PCF8563T + кварц FC-135, C304 18 пФ, BAT54C (D303) и R307 от CR2032; Q711/Q721 → AOD66923 (DPAK, свой footprint с нумерацией S1/2/3 G4 D5), D711/D721 → SS5P10 (TO-277A); L101 → FXL0630-100-M, L902 → PSPMAA0604-220M (площадка FXL0630). Переразмещены узлы ключей CH1/CH2 и RTC (29 деталей). Прошивка определяет PCF8563 или DS3231. 165 компонентов / 66 кодов, $31,62 на плату. Проверка после слияния: исправлен RMS обмотки L902 (1,233 А вместо входного 1,085 А), уточнены ток PCF8563 и ограничения батарейного диодного ИЛИ. [COST_DOWN_020.md](https://github.com/nikolajevs/ai/blob/1887d866ac820a41e9d1717056d188d7af6e6b51/pcb/PCB_V1/COST_DOWN_020.md) |
| 0.19 | 29.09.2026 | ветка `pcb-cost-down`, PR #11 | Удешевление без изменения платы: выход LED — TDK C3225X7R2A106K250AC, 22 мкФ 3,3 В — Samsung X5R, 10 мкФ/50 В — Taiyo Yuden, C602 = C201 10 мкФ, D601 = SMBJ26CA, R501/R511/R521 = 33 Ом, F904 = 3 А. Посадочные места, соединения и положения деталей прежние; плата синхронизирована по 17 номиналам. 65 закупочных кодов, детали $37,50/плату. ERC 0/0, DRC 0 |
| 0.18 | 29.09.2026 | ветка `pcb-simplify` | Упрощение до трассировки: удалены D401–D403, R409 и дублирующие R701/R702. Унифицированы 1k, 47k, 100k, 100n и 22u/25V; делитель 3,3 В теперь 1%, L101 SRP7028A-100M. 161 компонент / 69 закупочных кодов. Сохранены позиции остальных деталей. ERC 0/0, DRC 0 геометрических нарушений, 336 неразведённых связей. Детали $39,82/плату; трассировка отложена |
| 0.17 | 28.09.2026 | ветка `pcb-placement` | Начальное размещение всех 167 компонентов на 100×100 мм, без крепёжных отверстий; все разъёмы по краям, батарейка снизу. Предварительный стек JLC7628 и правила KiCad. Интегрирован обзор PR #5: отверстия XT60/KANGNEX, корпуса DORABO, MYOUNG CR2032 и Bourns L101, выбранные MPN. R716 = 0,18 Ом (1,111 А), свет 75,66/78,72 Вт. ERC 0/0, DRC 0 нарушений геометрии; 350 связей ещё не разведены |
| 0.16 | 27.09.2026 | ветка `pcb-0.16` | Удалён F903: он дублировал F711 + F721 и имел наименьший запас. L711 возвращён на SRP1770TA-470M, R715 на 0,027 Ом: запас OCP канала 1 вырос с 0,34 до 3,17 А, потери в меди в худшем случае снизились с 1,22 до 0,77 Вт. ESP32 получил посадочное место без 12 переходных отверстий 0,2 мм, **DRC — 0 нарушений**. Порядок в документации: `DESIGN.md`, `CHANGELOG.md`, папки `history/`, общий скрипт `check_all.py`. Оценка цен отложена |
| 0.15 | 27.09.2026 | `11c4692`, слияние `179cbd9` | Питание AL8853 перенесено на +12V. Шесть SMT-предохранителей Littelfuse 451 (вентиляторы, помпа, LED CH1/CH2, вход buck). CH2 — 0,465 А (R726 0,43 Ом). L711 заменён на SRP1265A-470M / 0,043 Ом. Делитель 12 В — 150k/10k 0,1 %, полимерный C909 100 мкФ. Частичный ценовой аудит |
| 0.14 | 27.09.2026 | `dacd659` | **Переход на 24 В:** вход XT60PW-M без электронной защиты от переполюсовки, SMBJ26CA, мини-флажковые предохранители. Новый buck LMR16020 24 → 12 В для вентиляторов, драйвера PTC и TPS54202. PTC и помпа на 24 В. Линейки LED2 и LED3 объединены в один канал, третий AL8853 удалён. Кнопки TS-1187A, клеммы DORABO/KANGNEX |
| 0.13 | 27.09.2026 | `bdc7358` | Вход 12 В: идеальный диод LM74700 + NTMFS5C628NL, TVS SMBJ14CA; драйвер PTC от LDO TPS70950 (5 В) |
| — | 27.09.2026 | `c4d0346` | Параллельная ветка 12 В: отдельные предохранители и геометрия клемм. В `main` не вошла, идея перенесена в 0.15 |
| 0.12 | 27.09.2026 | `1b7e229` | Выбраны силовые дроссели, диоды и выходные MLCC LED-каналов; скрипт `analyze_led_power.py` |
| 0.11 | 27.09.2026 | `9d56c17` | RTC DS3231MZ (SOIC-8) вместо DS3231SN; ключи лент CSD19538Q3A |
| 0.10 | 27.09.2026 | `5795ac4` | Ключи лент DMT10H009LK3 (DPAK) |
| 0.9 | 27.09.2026 | `5aa7683` | AL8853 вместо LT3756; яркость через общий сигнал `LED_DIM` (U700) |
| 0.8 | 27.09.2026 | `0b52064` | Посадочные места LED-ключей; полный экспорт BOM из схемы |
| 0.7 | 27.09.2026 | `054cb55` | Исправлена распиновка силовых MOSFET и защита от переполюсовки |
| 0.6 | 27.09.2026 | `1b0206f` | Исправлен разрыв токового пути LED, добавлены конденсаторы boost |
| 0.5 | 27.09.2026 | `87ffa3d`, `d36e9df` | Уникальные обозначения; заготовка платы 100×100 мм, 4 слоя |
| 0.4 | 27.09.2026 | `f1c6dc8`, `a9eb854` | Входная защита 12 В, три LED-канала на LT3756; первый BOM |
| 0.3 | 26.09.2026 | `8cdf425` | Выходы: два вентилятора, помпа, ключ PTC |
| 0.2 | 26.09.2026 | `f6dbf3a` | RTC, microSD, защищённые интерфейсы SHT4x и поплавка |
| 0.1 | 26.09.2026 | `9f7c724` | Логическое питание TPS54202, ESP32-WROOM-32E, UART |

## Архив

Полные версии сокращённых документов до упрощения: [DESIGN.md](https://github.com/nikolajevs/ai/blob/f229255/pcb/PCB_V1/DESIGN.md), [ROUTING_PREP.md](https://github.com/nikolajevs/ai/blob/f229255/pcb/PCB_V1/ROUTING_PREP.md), [ROUTING.md](https://github.com/nikolajevs/ai/blob/f229255/pcb/PCB_V1/ROUTING.md).

Файлы ниже удалены из рабочего дерева 01.10.2026, чтобы в репозитории оставалось только актуальное. Ссылки ведут на коммит `1887d86` — последнее состояние, где они были. Локально: `git show 1887d86:<путь>`.

| Что | Ревизия | Содержание |
|---|---|---|
| [RTC_BACKUP_021.md](https://github.com/nikolajevs/ai/blob/1887d866ac820a41e9d1717056d188d7af6e6b51/pcb/PCB_V1/RTC_BACKUP_021.md) | 0.21 | Выбор диода RTC BAV170, проверка питания RTC, цены |
| [COST_DOWN_020.md](https://github.com/nikolajevs/ai/blob/1887d866ac820a41e9d1717056d188d7af6e6b51/pcb/PCB_V1/COST_DOWN_020.md) | 0.20 | Удешевление со сменой платы и прошивки: PCF8563, DPAK, TO-277A, дроссели 7 мм |
| [COST_DOWN.md](https://github.com/nikolajevs/ai/blob/1887d866ac820a41e9d1717056d188d7af6e6b51/pcb/PCB_V1/COST_DOWN.md) | 0.19 | Замены в тех же посадочных местах, отклонённые варианты |
| [SIMPLIFICATION.md](https://github.com/nikolajevs/ai/blob/1887d866ac820a41e9d1717056d188d7af6e6b51/pcb/PCB_V1/SIMPLIFICATION.md) | 0.18 | Удалённые детали, расчёты замен, компромисс по ESD microSD |
| [PRE_LAYOUT_PARTS_REVIEW.md](https://github.com/nikolajevs/ai/blob/1887d866ac820a41e9d1717056d188d7af6e6b51/pcb/PCB_V1/PRE_LAYOUT_PARTS_REVIEW.md) | 0.16–0.17 | Проверка MPN, посадочных мест и габаритов разъёмов перед размещением |
| [LAYOUT_PLAN.md](https://github.com/nikolajevs/ai/blob/1887d866ac820a41e9d1717056d188d7af6e6b51/pcb/PCB_V1/LAYOUT_PLAN.md) | 0.16–0.17 | Требования к размещению и разделение задач |
| [COST_REVIEW.md](https://github.com/nikolajevs/ai/blob/1887d866ac820a41e9d1717056d188d7af6e6b51/pcb/PCB_V1/COST_REVIEW.md) | 0.16 | Стоимость, склад, кандидаты на удешевление, сборка JLCPCB |
| [history/](https://github.com/nikolajevs/ai/tree/1887d866ac820a41e9d1717056d188d7af6e6b51/pcb/PCB_V1/history) | 0.1–0.15 | Документы 12-вольтовой версии и частичный снимок цен v15 |
| [review/](https://github.com/nikolajevs/ai/tree/1887d866ac820a41e9d1717056d188d7af6e6b51/pcb/review) | v16–v22 | Отчёты ERC/DRC, расчёты, цены, изображения листов и размещения по ревизиям |
| [review/history/](https://github.com/nikolajevs/ai/tree/1887d866ac820a41e9d1717056d188d7af6e6b51/pcb/review/history) | 0.1–0.15 | Отчёты и изображения 12-вольтовой версии |
| [снимки цен](https://github.com/nikolajevs/ai/tree/1887d866ac820a41e9d1717056d188d7af6e6b51/pcb/PCB_V1) | v16–v21 | `price_snapshot_v*.json`, `jlc_snapshot_v*.json` прежних ревизий |

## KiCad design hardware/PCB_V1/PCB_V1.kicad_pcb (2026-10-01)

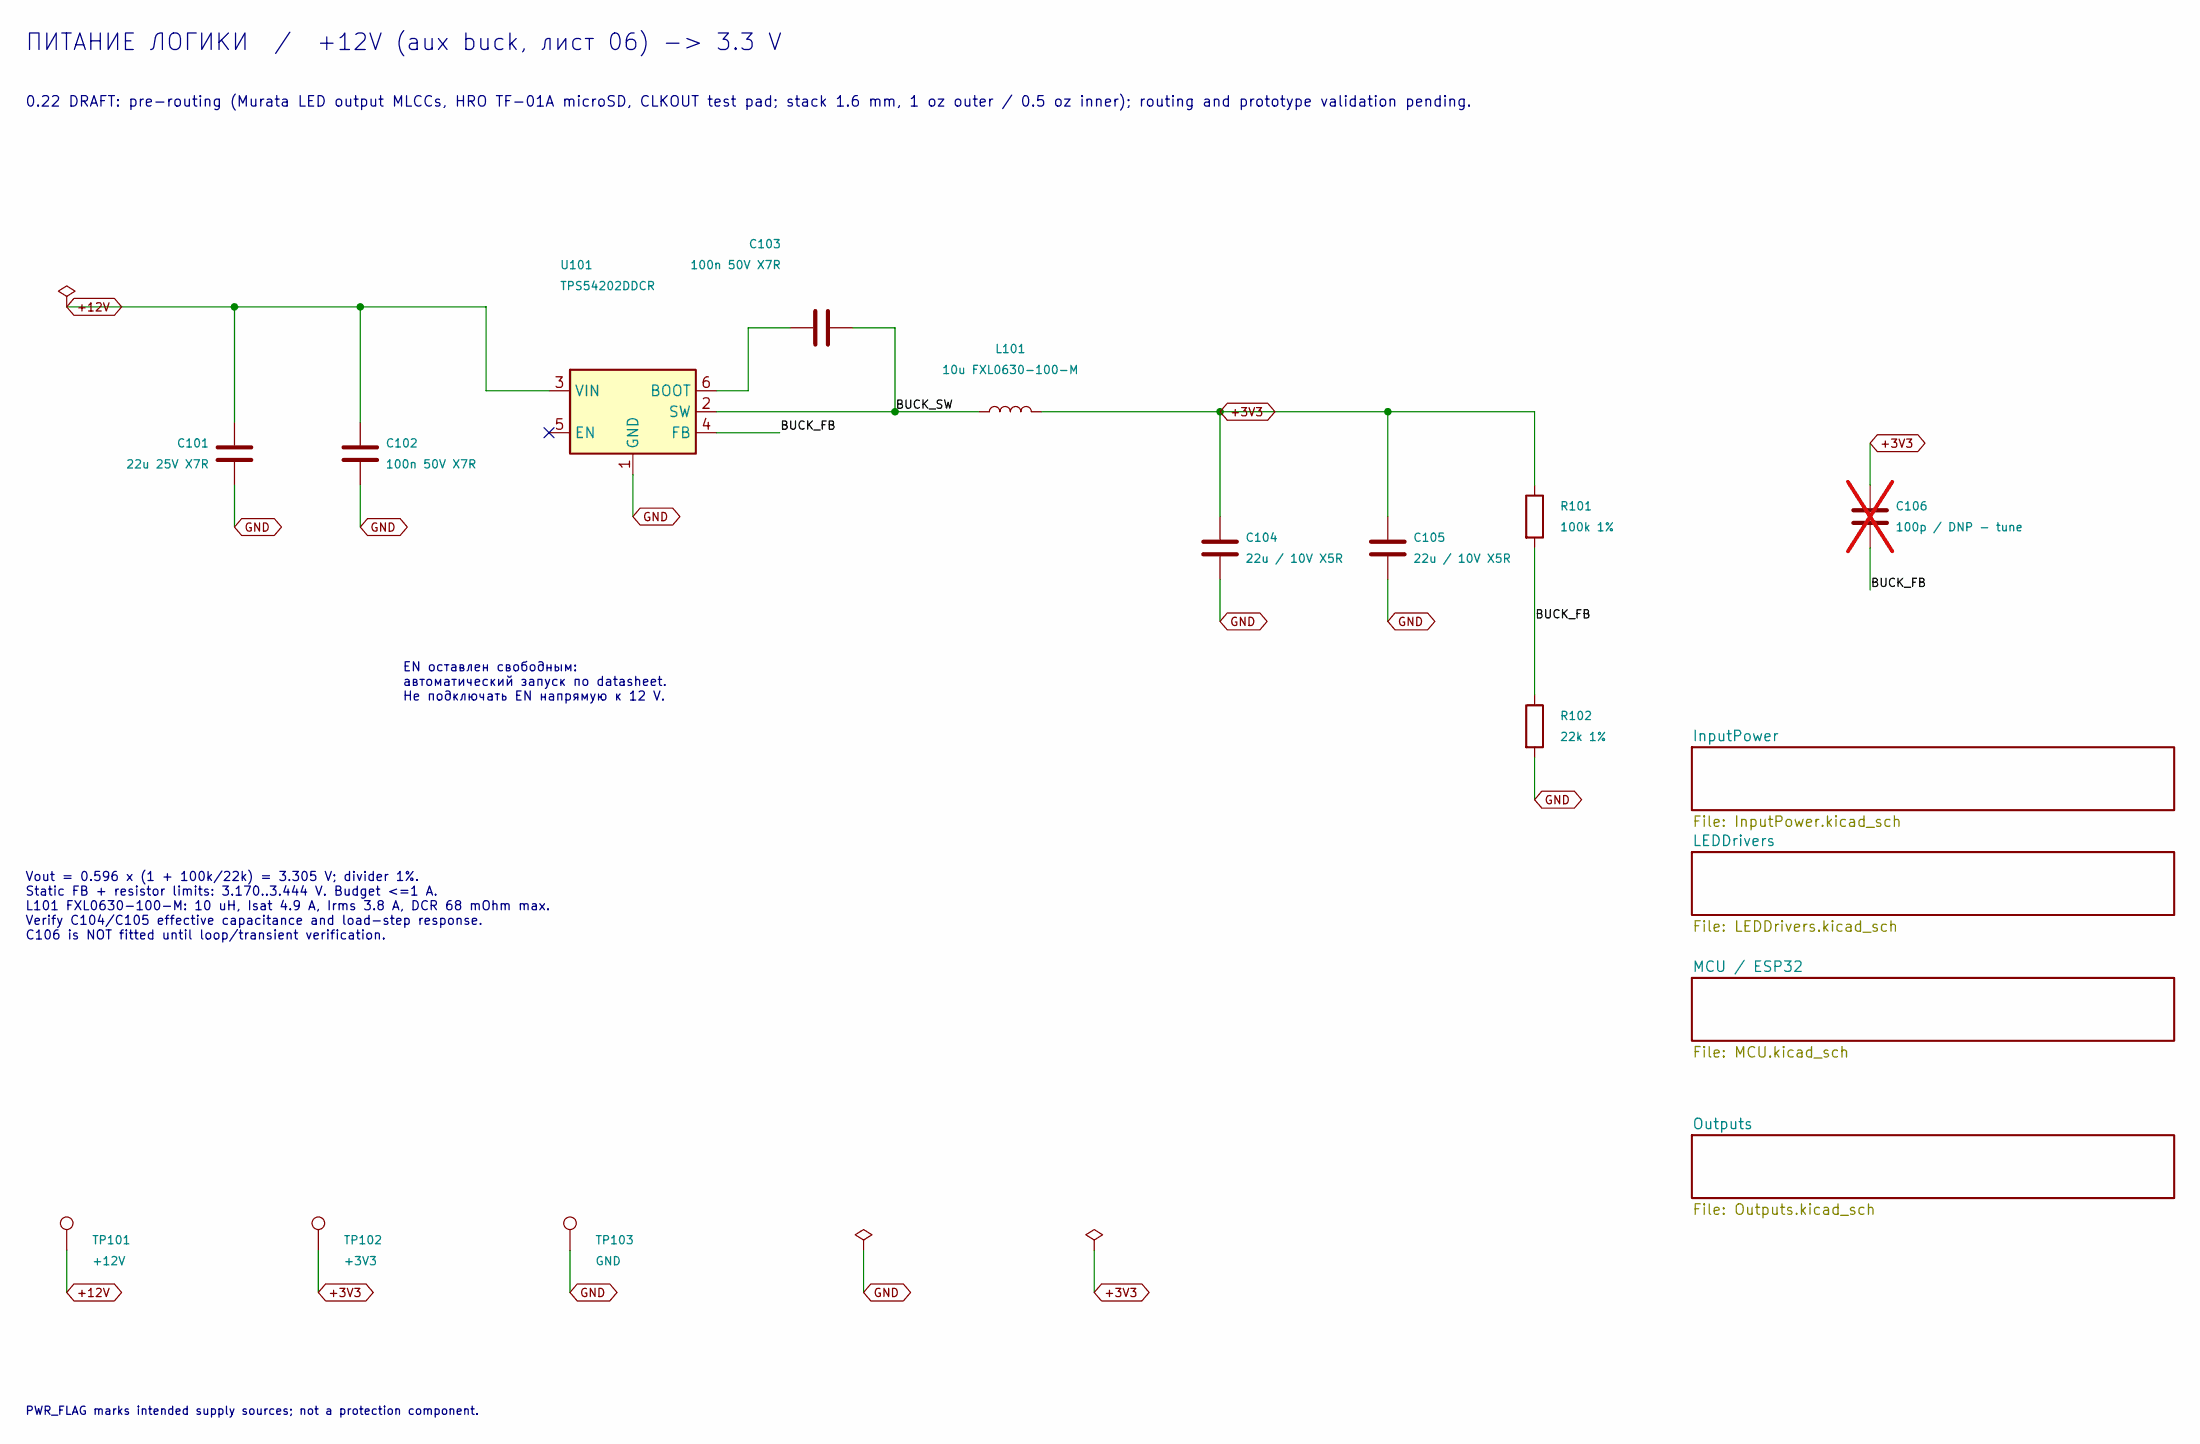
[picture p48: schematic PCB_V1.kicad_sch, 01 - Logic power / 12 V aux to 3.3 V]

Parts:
C101: 22u 25V X7R; C_1210_3225Metric; MPN CL32B226KAJNNNE; LCSC C309062
C102, C103: 100n 50V X7R; C_0603_1608Metric; MPN CL10B104KB8NNNC; LCSC C1591
C104, C105: 22u / 10V X5R; C_0805_2012Metric; MPN CL21A226MPQNNNE; LCSC C29277
C106: 100p / DNP - tune; C_0603_1608Metric; not fitted
L101: 10u FXL0630-100-M; L_Changjiang_FXL0630; MPN FXL0630-100-M; LCSC C167223
R101: 100k 1%; R_0603_1608Metric; MPN 0603WAF1003T5E; LCSC C25803
R102: 22k 1%; R_0603_1608Metric; MPN 0603WAF2202T5E; LCSC C31850
TP101: +12V; TestPoint_Pad_D2.0mm
TP102: +3V3; TestPoint_Pad_D2.0mm
TP103: GND; TestPoint_Pad_D2.0mm
U101: TPS54202DDCR; SOT-23-6

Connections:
+3V3: C104.1, C105.1, C106.1, L101.2, R101.1, TP102.1 (1_1); also elsewhere on the board
+12V: C101.1, C102.1, TP101.1 (1_1), U101.3 (VIN); also elsewhere on the board
/BUCK_FB: C106.2, R101.2, R102.1, U101.4 (FB)
/BUCK_SW: C103.2, L101.1, U101.2 (SW)
GND: C101.2, C102.2, C104.2, C105.2, R102.2, TP103.1 (1_1), U101.1 (GND); also elsewhere on the board
unnamed: C103.1, U101.6 (BOOT)

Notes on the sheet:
Vout = 0.596 x (1 + 100k/22k) = 3.305 V; divider 1%. Static FB + resistor limits: 3.170..3.444 V. Budget <=1 A. L101 FXL0630-100-M: 10 uH, Isat 4.9 A, Irms 3.8 A, DCR 68 mOhm max. Verify C104/C105 effective capacitance and load-step response. C106 is NOT fitted until loop/transient verification.
ПИТАНИЕ ЛОГИКИ / +12V (aux buck, лист 06) -> 3.3 V
EN оставлен свободным: автоматический запуск по datasheet. Не подключать EN напрямую к 12 V.
PWR_FLAG marks intended supply sources; not a protection component.
0.22 DRAFT: pre-routing (Murata LED output MLCCs, HRO TF-01A microSD, CLKOUT test pad; stack 1.6 mm, 1 oz outer / 0.5 oz inner); routing and prototype validation pending.

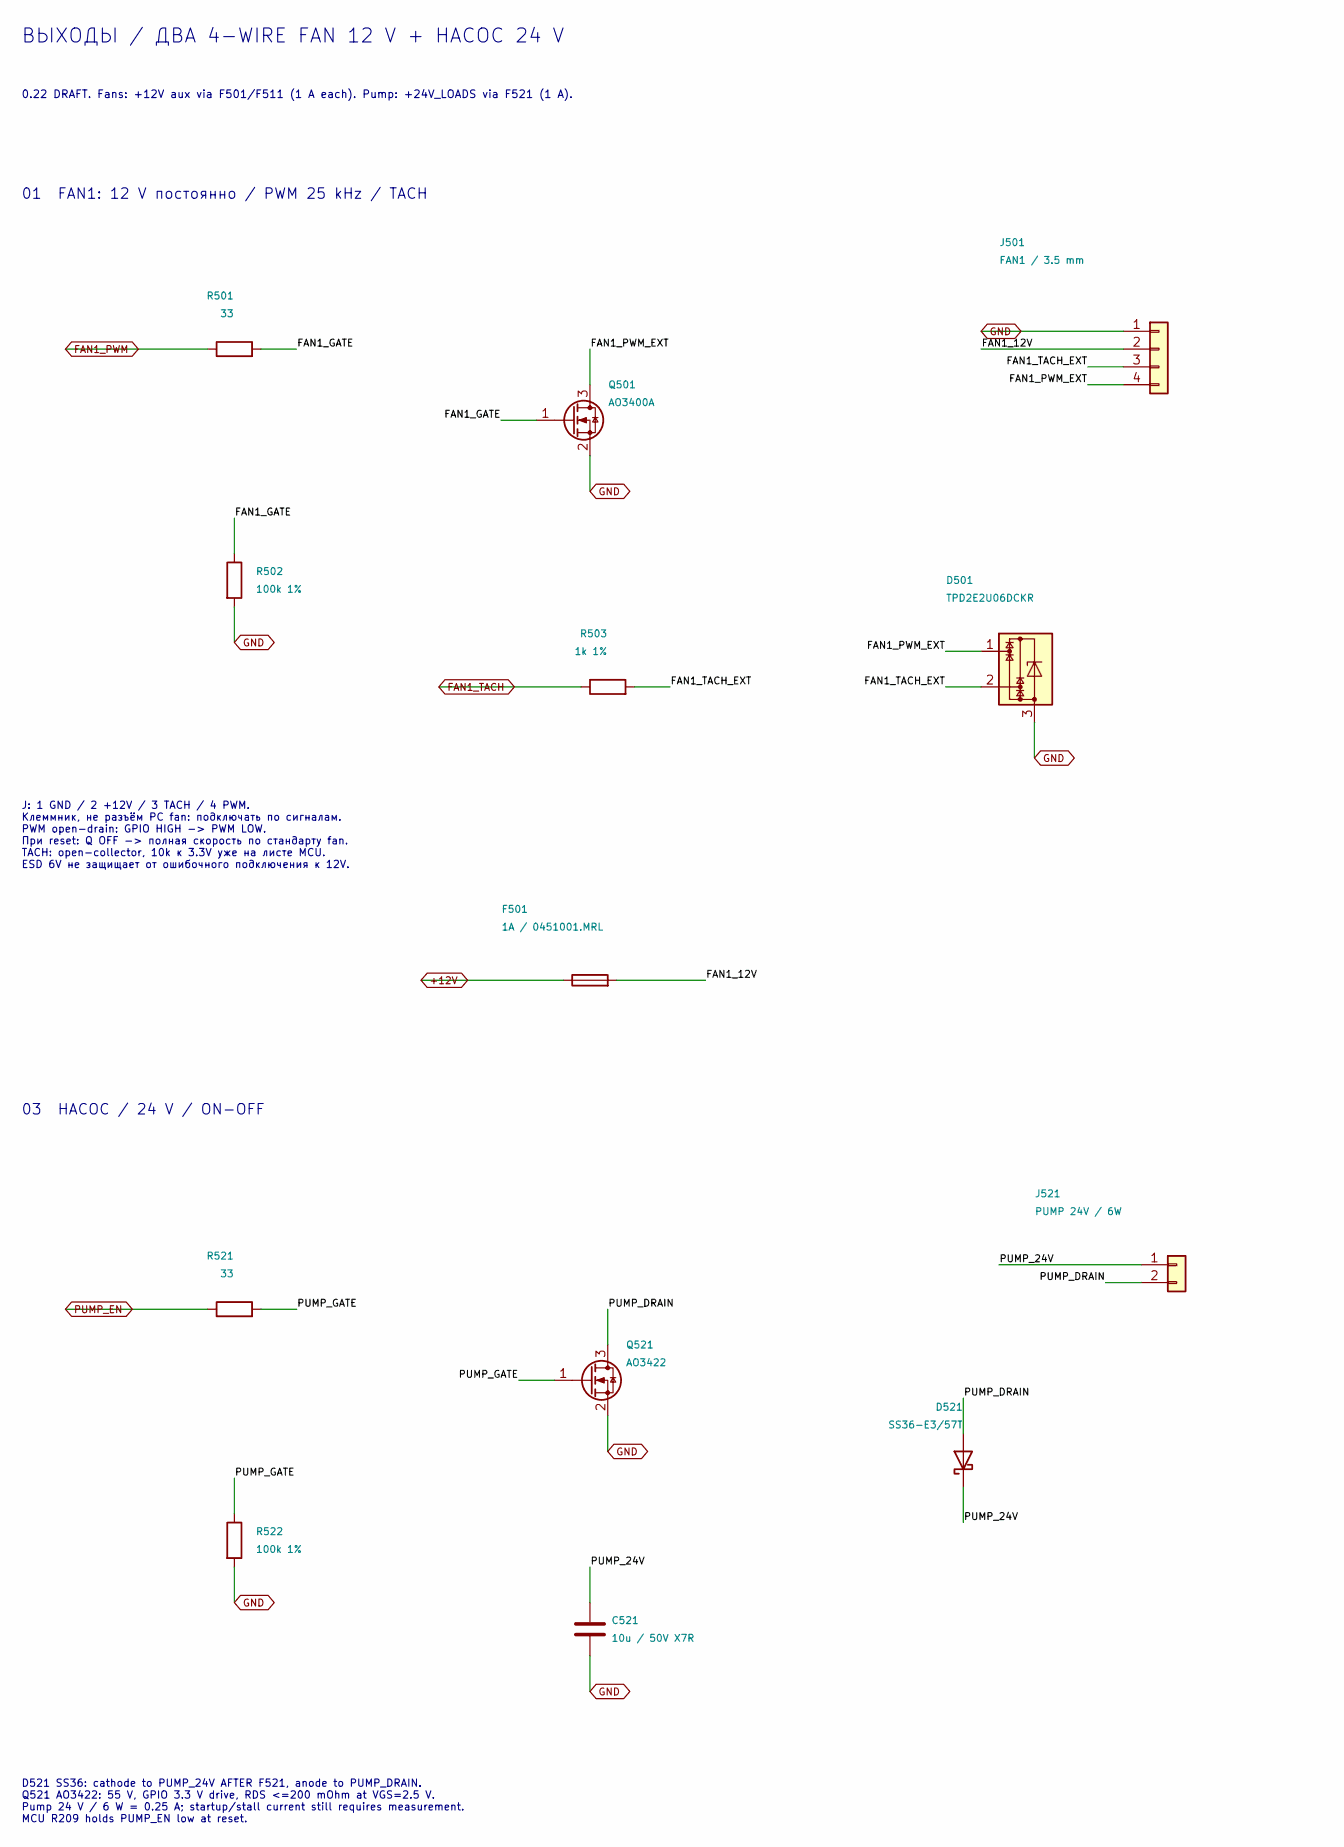
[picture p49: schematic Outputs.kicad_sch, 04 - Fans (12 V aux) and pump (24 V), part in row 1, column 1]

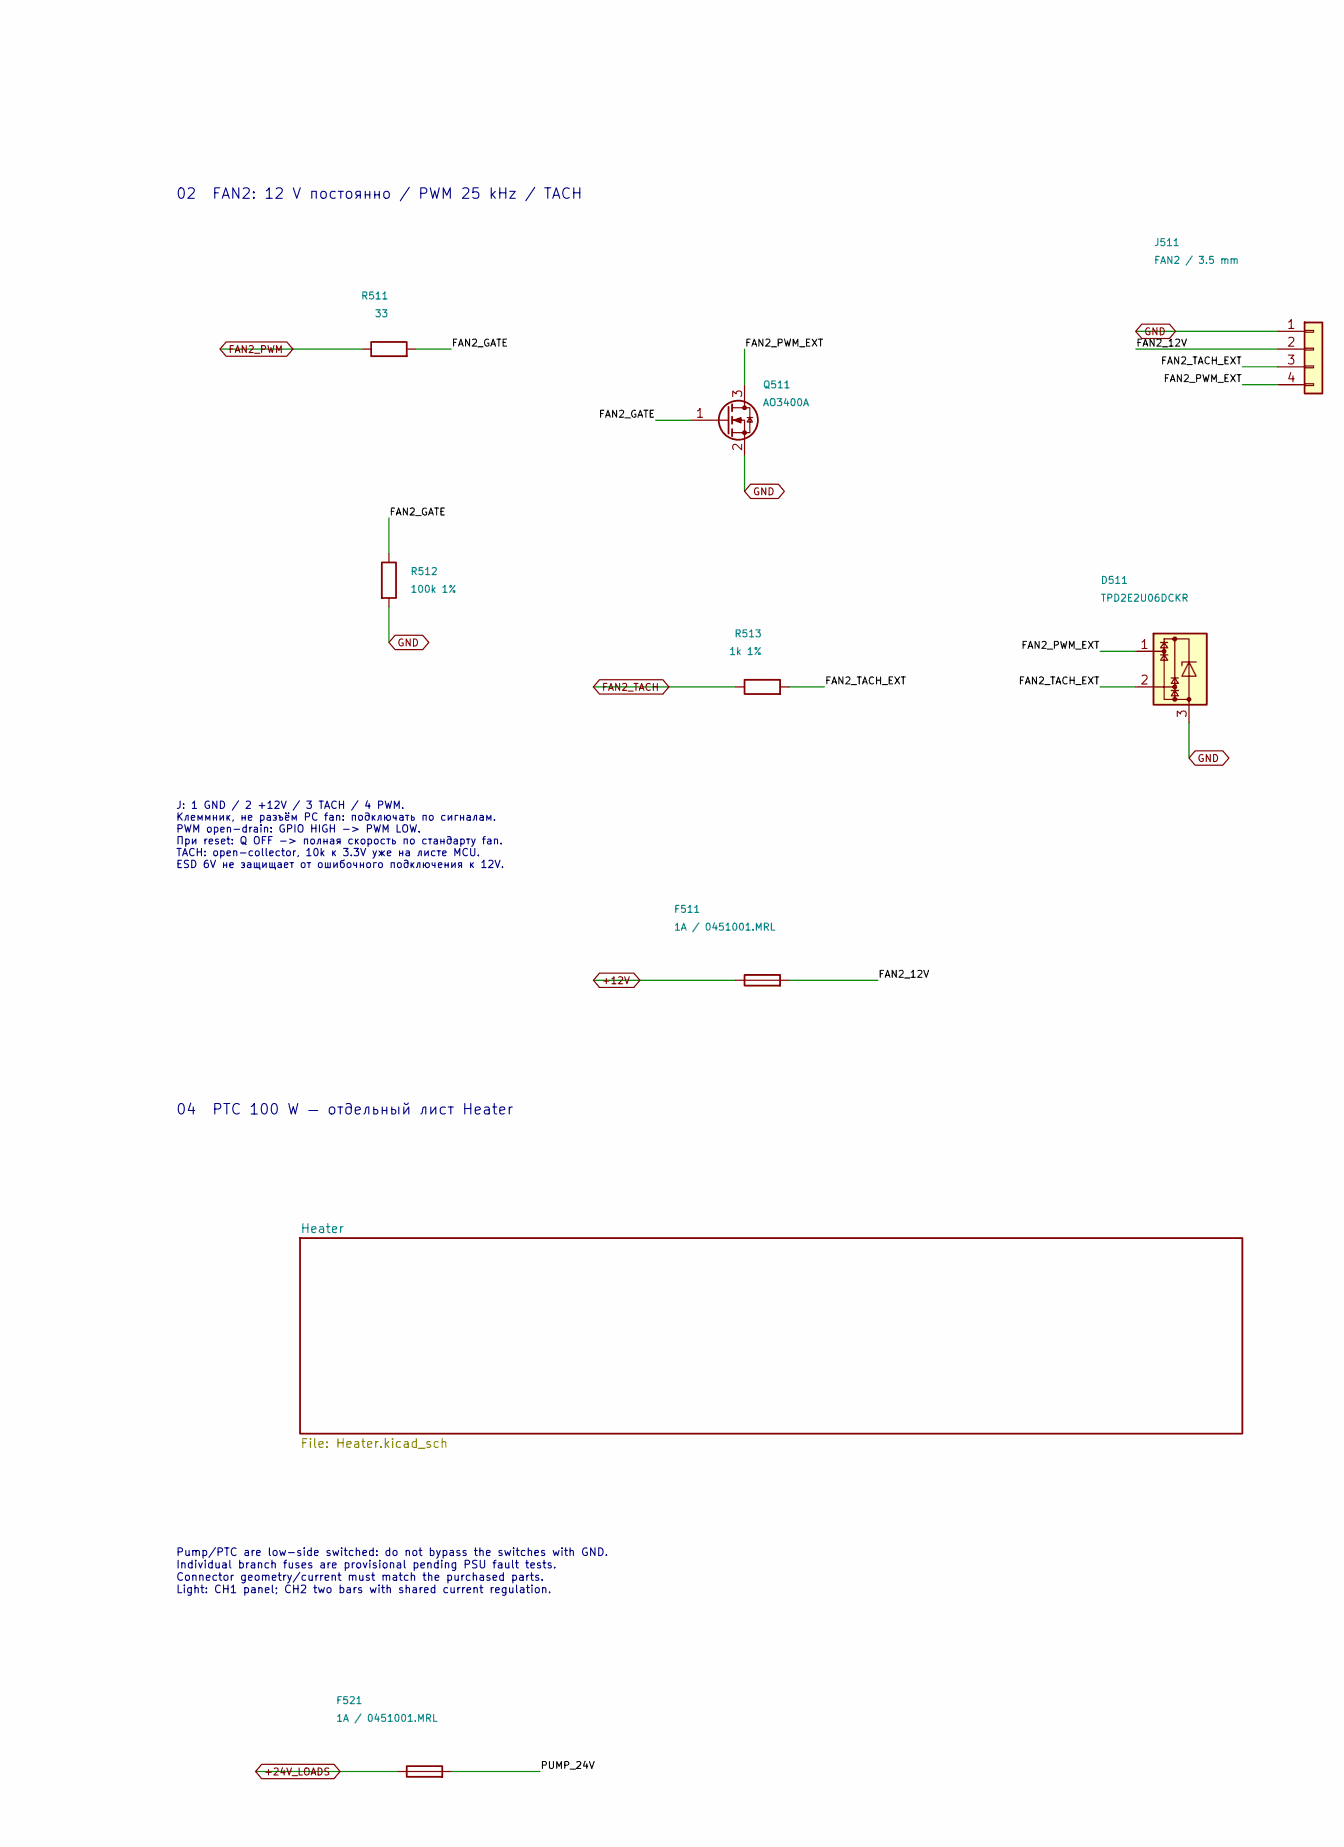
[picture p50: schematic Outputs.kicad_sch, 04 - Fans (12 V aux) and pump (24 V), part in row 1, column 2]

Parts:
C521: 10u / 50V X7R; C_1210_3225Metric; MPN UMK325AB7106KMHP; LCSC C386166
D501, D511: TPD2E2U06DCKR; SOT-323_SC-70
D521: SS36-E3/57T; D_SMC; MPN SS36-E3/57T; LCSC C35722
F501, F511, F521: 1A / 0451001.MRL; Fuse_Littelfuse_451; MPN 0451001.MRL; LCSC C3099
J501: FAN1 / 3.5 mm; TerminalBlock_DORABO_DB125-3.5_1x04_P3.50mm_Horizontal; MPN DB125-3.5-4P-GN-S; LCSC C2757925
J511: FAN2 / 3.5 mm; TerminalBlock_DORABO_DB125-3.5_1x04_P3.50mm_Horizontal; MPN DB125-3.5-4P-GN-S; LCSC C2757925
J521: PUMP 24V / 6W; TerminalBlock_DORABO_DB125-3.5_1x02_P3.50mm_Horizontal; MPN DB125-3.5-2P-GN-S; LCSC C466970
Q501, Q511: AO3400A; SOT-23
Q521: AO3422; SOT-23; MPN AO3422; LCSC C37130
R501, R511, R521: 33; R_0603_1608Metric
R502, R512, R522: 100k 1%; R_0603_1608Metric; MPN 0603WAF1003T5E; LCSC C25803
R503, R513: 1k 1%; R_0603_1608Metric; MPN 0603WAF1001T5E; LCSC C21190

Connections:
+12V: F501.1, F511.1; also elsewhere on the board
+24V_LOADS: F521.1; also elsewhere on the board
/Outputs/FAN1_12V: F501.2, J501.2
/Outputs/FAN1_GATE: Q501.1 (G), R501.2, R502.1
/Outputs/FAN1_PWM_EXT: D501.1, J501.4, Q501.3 (D)
/Outputs/FAN1_TACH_EXT: D501.2, J501.3, R503.2
/Outputs/FAN2_12V: F511.2, J511.2
/Outputs/FAN2_GATE: Q511.1 (G), R511.2, R512.1
/Outputs/FAN2_PWM_EXT: D511.1, J511.4, Q511.3 (D)
/Outputs/FAN2_TACH_EXT: D511.2, J511.3, R513.2
/Outputs/PUMP_24V: C521.1, D521.1 (K), F521.2, J521.1
/Outputs/PUMP_DRAIN: D521.2 (A), J521.2, Q521.3 (D)
/Outputs/PUMP_GATE: Q521.1 (G), R521.2, R522.1
FAN1_PWM: R501.1; also elsewhere on the board
FAN1_TACH: R503.1; also elsewhere on the board
FAN2_PWM: R511.1; also elsewhere on the board
FAN2_TACH: R513.1; also elsewhere on the board
GND: C521.2, D501.3, D511.3, J501.1, J511.1, Q501.2 (S), Q511.2 (S), Q521.2 (S), R502.2, R512.2, R522.2; also elsewhere on the board
PUMP_EN: R521.1; also elsewhere on the board

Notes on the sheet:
04 PTC 100 W — отдельный лист Heater
J: 1 GND / 2 +12V / 3 TACH / 4 PWM. Клеммник, не разъём PC fan: подключать по сигналам. PWM open-drain: GPIO HIGH -> PWM LOW. При reset: Q OFF -> полная скорость по стандарту fan. TACH: open-collector, 10k к 3.3V уже на листе MCU. ESD 6V не защищает от ошибочного подключения к 12V.
D521 SS36: cathode to PUMP_24V AFTER F521, anode to PUMP_DRAIN. Q521 AO3422: 55 V, GPIO 3.3 V drive, RDS <=200 mOhm at VGS=2.5 V. Pump 24 V / 6 W = 0.25 A; startup/stall current still requires measurement. MCU R209 holds PUMP_EN low at reset.
0.22 DRAFT. Fans: +12V aux via F501/F511 (1 A each). Pump: +24V_LOADS via F521 (1 A).
03 НАСОС / 24 V / ON-OFF
Pump/PTC are low-side switched: do not bypass the switches with GND. Individual branch fuses are provisional pending PSU fault tests. Connector geometry/current must match the purchased parts. Light: CH1 panel; CH2 two bars with shared current regulation.
02 FAN2: 12 V постоянно / PWM 25 kHz / TACH
01 FAN1: 12 V постоянно / PWM 25 kHz / TACH
ВЫХОДЫ / ДВА 4-WIRE FAN 12 V + НАСОС 24 V

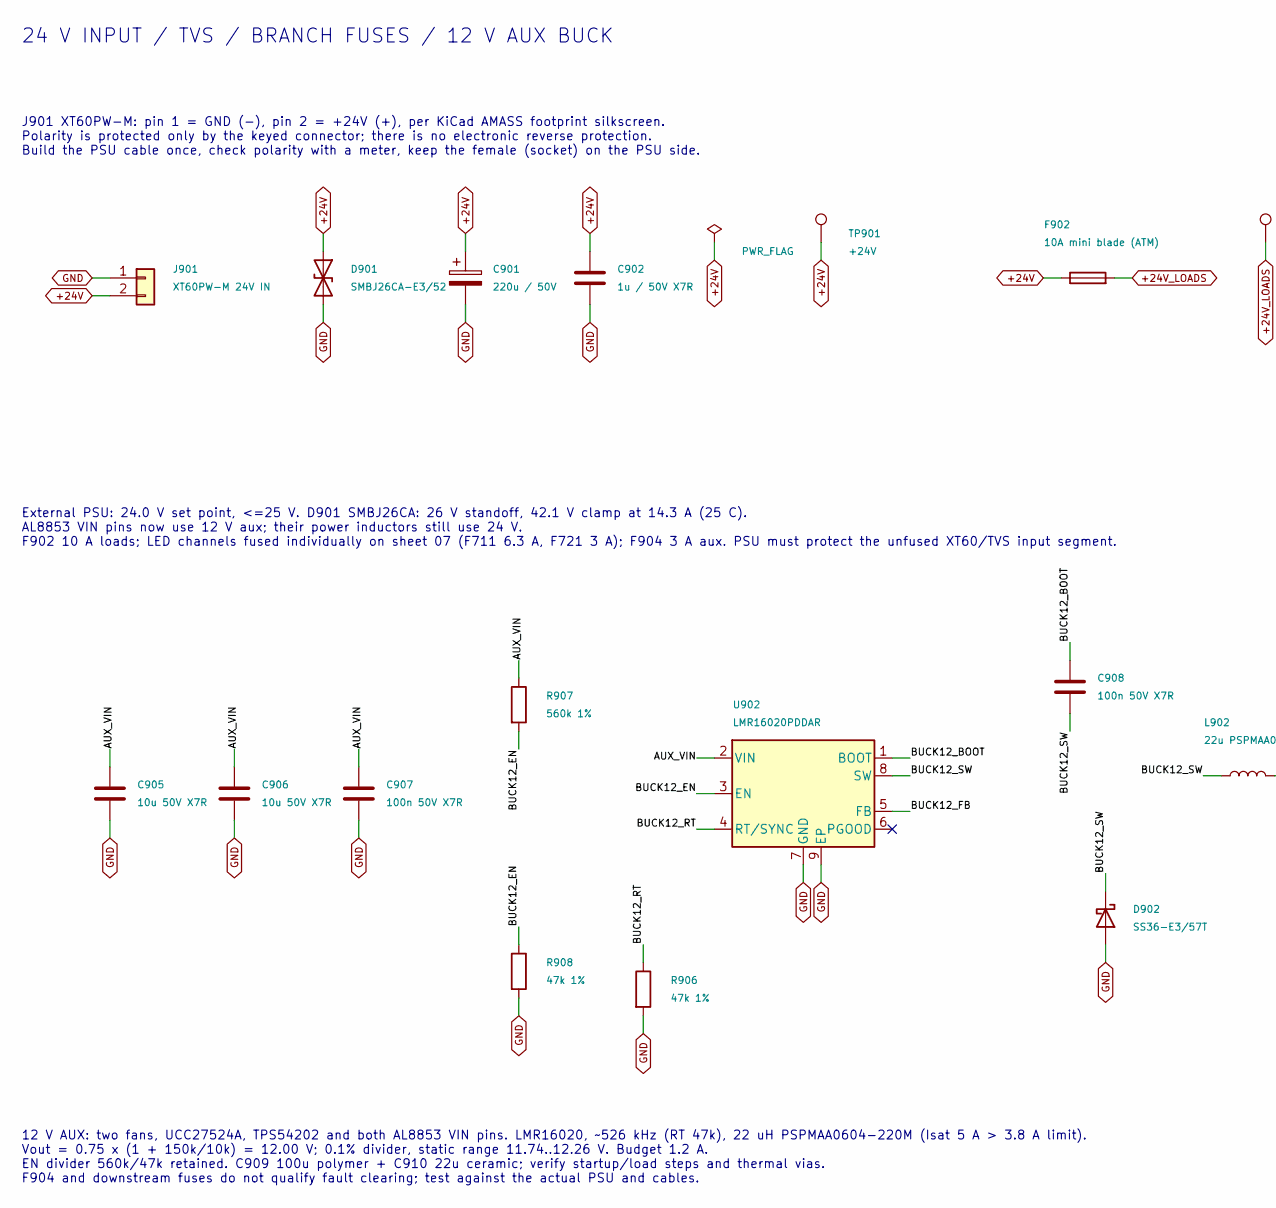
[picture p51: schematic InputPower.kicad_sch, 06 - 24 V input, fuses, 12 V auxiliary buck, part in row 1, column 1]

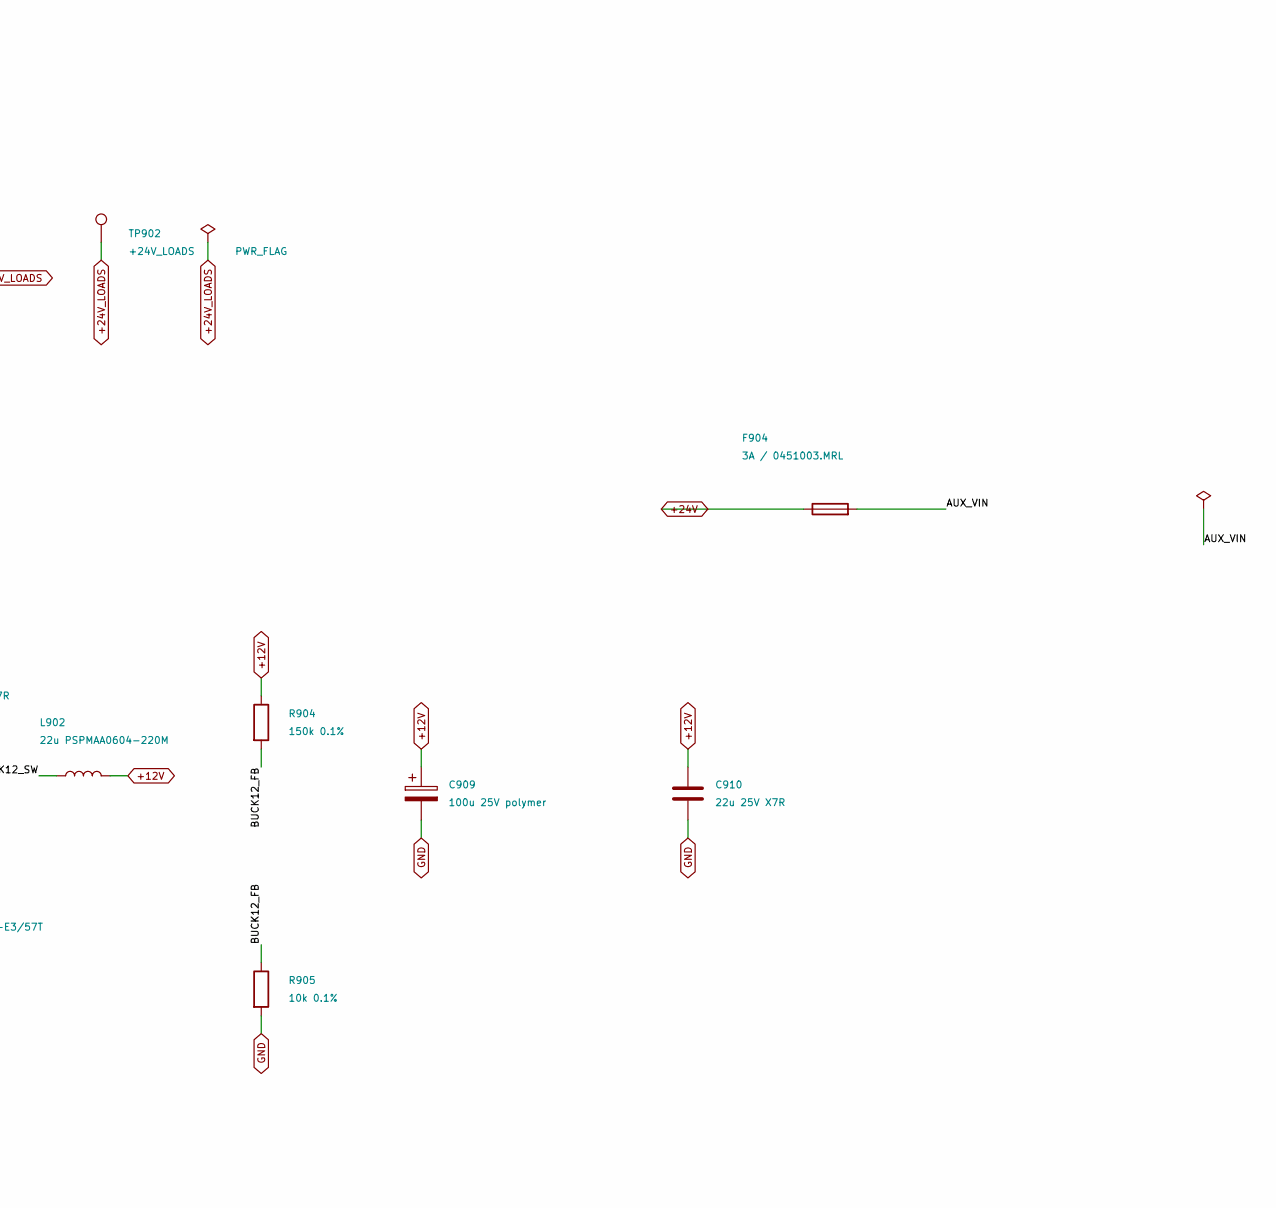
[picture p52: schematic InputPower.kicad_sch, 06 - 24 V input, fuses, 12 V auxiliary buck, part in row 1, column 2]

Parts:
C901: 220u / 50V; CP_Elec_10x10.5; MPN EEEFK1H221P; LCSC C178549
C902: 1u / 50V X7R; C_1210_3225Metric; MPN CL32B105KBHNNNE; LCSC C40708
C905, C906: 10u 50V X7R; C_1210_3225Metric; MPN UMK325AB7106KMHP; LCSC C386166
C907, C908: 100n 50V X7R; C_0603_1608Metric; MPN CL10B104KB8NNNC; LCSC C1591
C909: 100u 25V polymer; CP_Elec_8x6.9; MPN 25SVPF100M; LCSC C136279
C910: 22u 25V X7R; C_1210_3225Metric; MPN CL32B226KAJNNNE; LCSC C309062
D901: SMBJ26CA-E3/52; D_SMB; MPN SMBJ26CA-E3/52; LCSC C515606
D902: SS36-E3/57T; D_SMC; MPN SS36-E3/57T; LCSC C35722
F902: 10A mini blade (ATM); Fuseholder_Blade_Mini_XFCN_XF-508P; MPN XF-508P-B-B; LCSC C19727305
F904: 3A / 0451003.MRL; Fuse_Littelfuse_451; MPN 0451003.MRL; LCSC C13982
J901: XT60PW-M 24V IN; AMASS_XT60PW-M_1x02_P7.20mm_Horizontal; MPN XT60PW-M; LCSC C98732
L902: 22u PSPMAA0604-220M; L_Changjiang_FXL0630; MPN PSPMAA0604-220M-ANP; LCSC C53190553
R904: 150k 0.1%; R_0603_1608Metric; MPN RT0603BRD07150KL; LCSC C326734
R905: 10k 0.1%; R_0603_1608Metric; MPN RT0603BRD0710KL; LCSC C95204
R906, R908: 47k 1%; R_0603_1608Metric; MPN RC0603FR-0747KL; LCSC C105579
R907: 560k 1%; R_0603_1608Metric; MPN 0603WAF5603T5E; LCSC C23203
TP901: +24V; TestPoint_Pad_D2.0mm
TP902: +24V_LOADS; TestPoint_Pad_D2.0mm
U902: LMR16020PDDAR; SOIC-8-1EP_3.9x4.9mm_P1.27mm_EP2.95x4.9mm_Mask2.71x3.4mm; MPN LMR16020PDDAR; LCSC C190006

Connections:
+12V: C909.1, C910.1, L902.2, R904.1; also elsewhere on the board
+24V: C901.1, C902.1, D901.1 (A1), F902.1, F904.1, J901.2, TP901.1 (1_1); also elsewhere on the board
+24V_LOADS: F902.2, TP902.1 (1_1); also elsewhere on the board
/InputPower/AUX_VIN: C905.1, C906.1, C907.1, F904.2, R907.1, U902.2 (VIN)
/InputPower/BUCK12_BOOT: C908.1, U902.1 (BOOT)
/InputPower/BUCK12_EN: R907.2, R908.1, U902.3 (EN)
/InputPower/BUCK12_FB: R904.2, R905.1, U902.5 (FB)
/InputPower/BUCK12_RT: R906.1, U902.4 (RT/SYNC)
/InputPower/BUCK12_SW: C908.2, D902.1 (K), L902.1, U902.8 (SW)
GND: C901.2, C902.2, C905.2, C906.2, C907.2, C909.2, C910.2, D901.2 (A2), D902.2 (A), J901.1, R905.2, R906.2, R908.2, U902.7 (GND), U902.9 (EP); also elsewhere on the board

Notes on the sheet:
24 V INPUT / TVS / BRANCH FUSES / 12 V AUX BUCK
J901 XT60PW-M: pin 1 = GND (-), pin 2 = +24V (+), per KiCad AMASS footprint silkscreen. Polarity is protected only by the keyed connector; there is no electronic reverse protection. Build the PSU cable once, check polarity with a meter, keep the female (socket) on the PSU side.
External PSU: 24.0 V set point, <=25 V. D901 SMBJ26CA: 26 V standoff, 42.1 V clamp at 14.3 A (25 C). AL8853 VIN pins now use 12 V aux; their power inductors still use 24 V. F902 10 A loads; LED channels fused individually on sheet 07 (F711 6.3 A, F721 3 A); F904 3 A aux. PSU must protect the unfuse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
12 V AUX: two fans, UCC27524A, TPS54202 and both AL8853 VIN pins. LMR16020, ~526 kHz (RT 47k), 22 uH PSPMAA0604-220M (Isat 5 A > 3.8 A limit). Vout = 0.75 x (1 + 150k/10k) = 12.00 V; 0.1% divider, static range 11.74..12.26 V. Budget 1.2 A. EN divider 560k/47k retained. C909 100u polymer + C910 22u 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

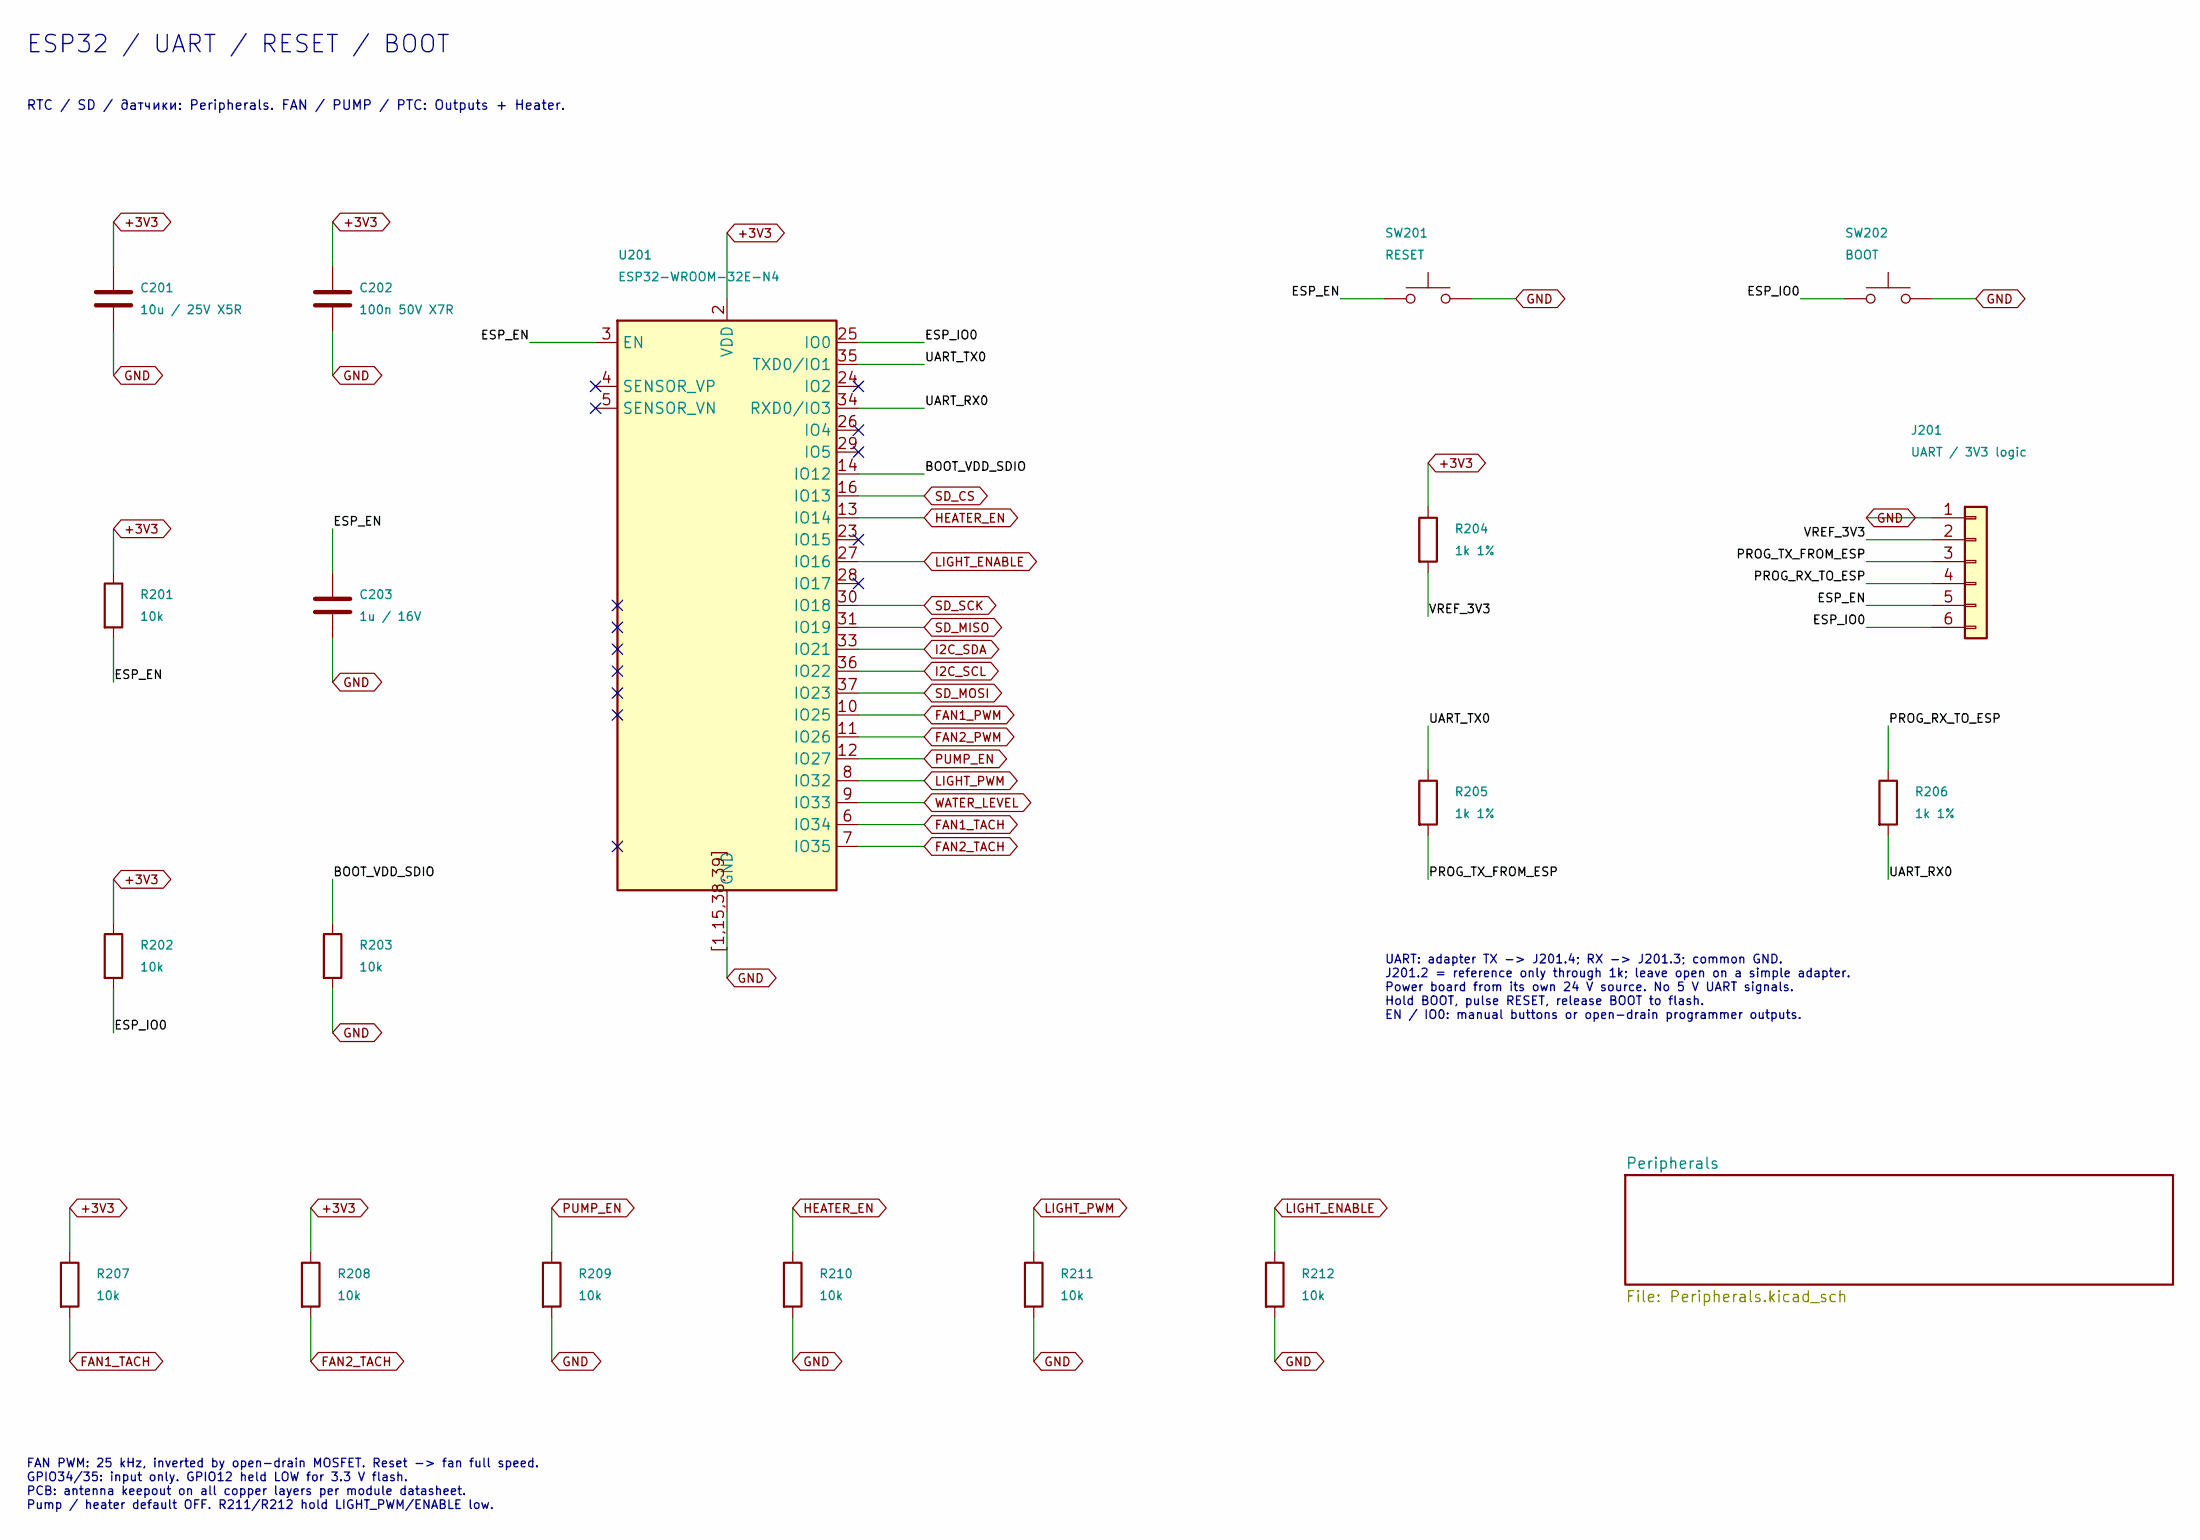
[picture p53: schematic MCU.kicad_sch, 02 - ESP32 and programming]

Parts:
C201: 10u / 25V X5R; C_0805_2012Metric; MPN CL21A106KAYNNNE; LCSC C15850
C202: 100n 50V X7R; C_0603_1608Metric; MPN CL10B104KB8NNNC; LCSC C1591
C203: 1u / 16V; C_0603_1608Metric
J201: UART / 3V3 logic; PinHeader_1x06_P2.54mm_Vertical
R201, R202, R203, R207, R208, R209, R210, R211, R212: 10k; R_0603_1608Metric
R204, R205, R206: 1k 1%; R_0603_1608Metric; MPN 0603WAF1001T5E; LCSC C21190
SW201: RESET; SW_Push_1P1T_XKB_TS-1187A; MPN TS-1187A-B-A-B; LCSC C318884
SW202: BOOT; SW_Push_1P1T_XKB_TS-1187A; MPN TS-1187A-B-A-B; LCSC C318884
U201: ESP32-WROOM-32E-N4; ESP32-WROOM-32E_NoVias; MPN ESP32-WROOM-32E-N4; LCSC C701341

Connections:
+3V3: C201.1, C202.1, R201.1, R202.1, R204.1, R207.1, R208.1, U201.2 (VDD); also elsewhere on the board
/MCU / ESP32/BOOT_VDD_SDIO: R203.1, U201.14 (IO12)
/MCU / ESP32/ESP_EN: C203.1, J201.5, R201.2, SW201.1, U201.3 (EN)
/MCU / ESP32/ESP_IO0: J201.6, R202.2, SW202.1, U201.25 (IO0)
/MCU / ESP32/PROG_RX_TO_ESP: J201.4, R206.1
/MCU / ESP32/PROG_TX_FROM_ESP: J201.3, R205.2
/MCU / ESP32/UART_RX0: R206.2, U201.34 (RXD0/IO3)
/MCU / ESP32/UART_TX0: R205.1, U201.35 (TXD0/IO1)
/MCU / ESP32/VREF_3V3: J201.2, R204.2
FAN1_PWM: U201.10 (IO25); also elsewhere on the board
FAN1_TACH: R207.2, U201.6 (IO34); also elsewhere on the board
FAN2_PWM: U201.11 (IO26); also elsewhere on the board
FAN2_TACH: R208.2, U201.7 (IO35); also elsewhere on the board
GND: C201.2, C202.2, C203.2, J201.1, R203.2, R209.2, R210.2, R211.2, R212.2, SW201.2, SW202.2, U201.1, U201.15, U201.38, U201.39, U201.[1,15,38,39] (GND); also elsewhere on the board
HEATER_EN: R210.1, U201.13 (IO14); also elsewhere on the board
I2C_SCL: U201.36 (IO22); also elsewhere on the board
I2C_SDA: U201.33 (IO21); also elsewhere on the board
LIGHT_ENABLE: R212.1, U201.27 (IO16); also elsewhere on the board
LIGHT_PWM: R211.1, U201.8 (IO32); also elsewhere on the board
PUMP_EN: R209.1, U201.12 (IO27); also elsewhere on the board
SD_CS: U201.16 (IO13); also elsewhere on the board
SD_MISO: U201.31 (IO19); also elsewhere on the board
SD_MOSI: U201.37 (IO23); also elsewhere on the board
SD_SCK: U201.30 (IO18); also elsewhere on the board
WATER_LEVEL: U201.9 (IO33); also elsewhere on the board

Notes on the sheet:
UART: adapter TX -> J201.4; RX -> J201.3; common GND. J201.2 = reference only through 1k; leave open on a simple adapter. Power board from its own 24 V source. No 5 V UART signals. Hold BOOT, pulse RESET, release BOOT to flash. EN / IO0: manual buttons or open-drain programmer outputs.
RTC / SD / датчики: Peripherals. FAN / PUMP / PTC: Outputs + Heater.
FAN PWM: 25 kHz, inverted by open-drain MOSFET. Reset -> fan full speed. GPIO34/35: input only. GPIO12 held LOW for 3.3 V flash. PCB: antenna keepout on all copper layers per module datasheet. Pump / heater default OFF. R211/R212 hold LIGHT_PWM/ENABLE low.
ESP32 / UART / RESET / BOOT

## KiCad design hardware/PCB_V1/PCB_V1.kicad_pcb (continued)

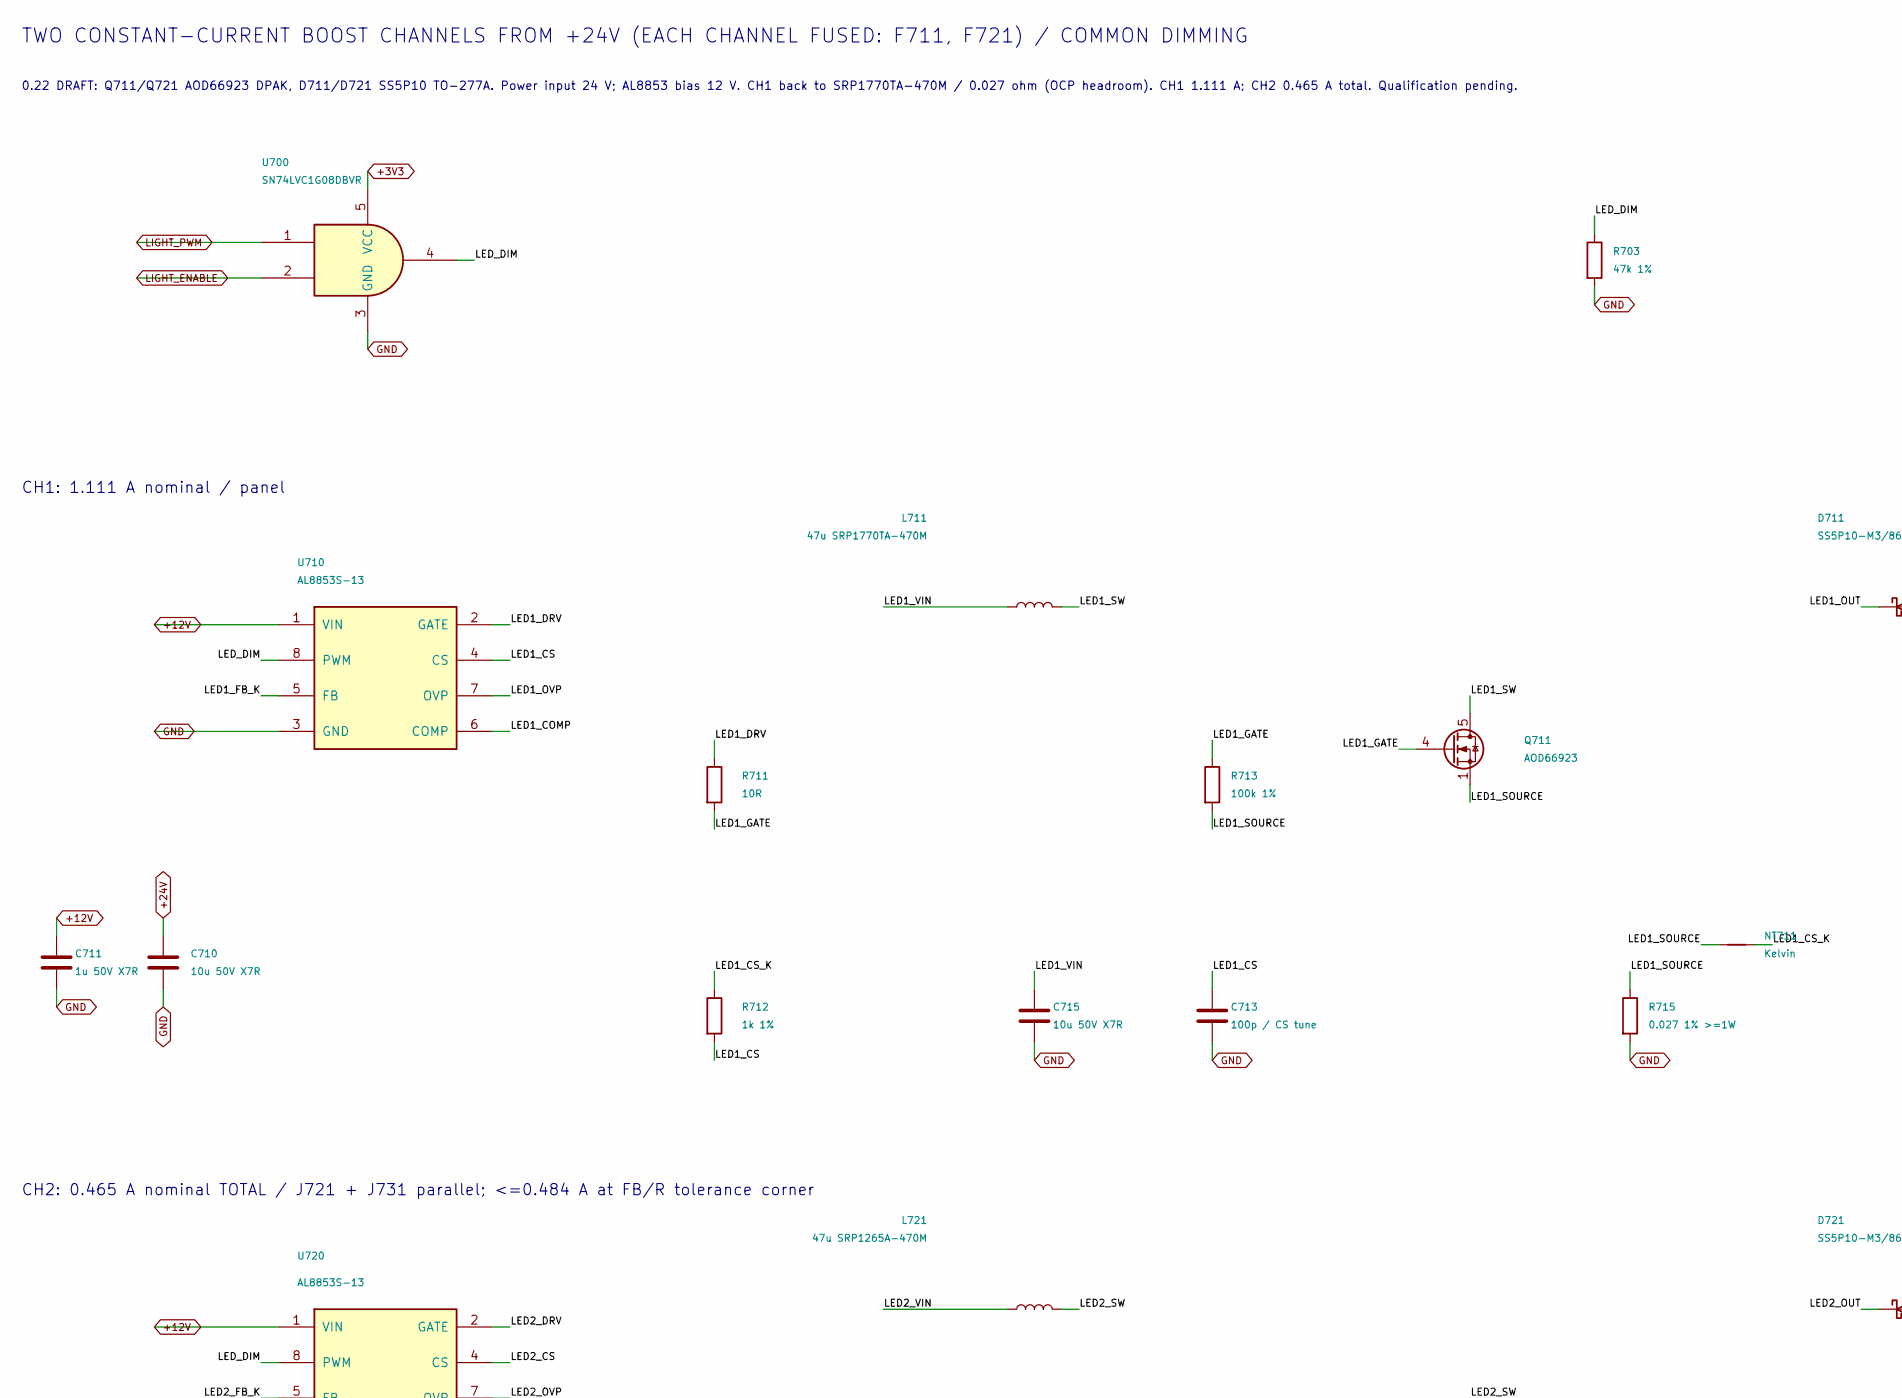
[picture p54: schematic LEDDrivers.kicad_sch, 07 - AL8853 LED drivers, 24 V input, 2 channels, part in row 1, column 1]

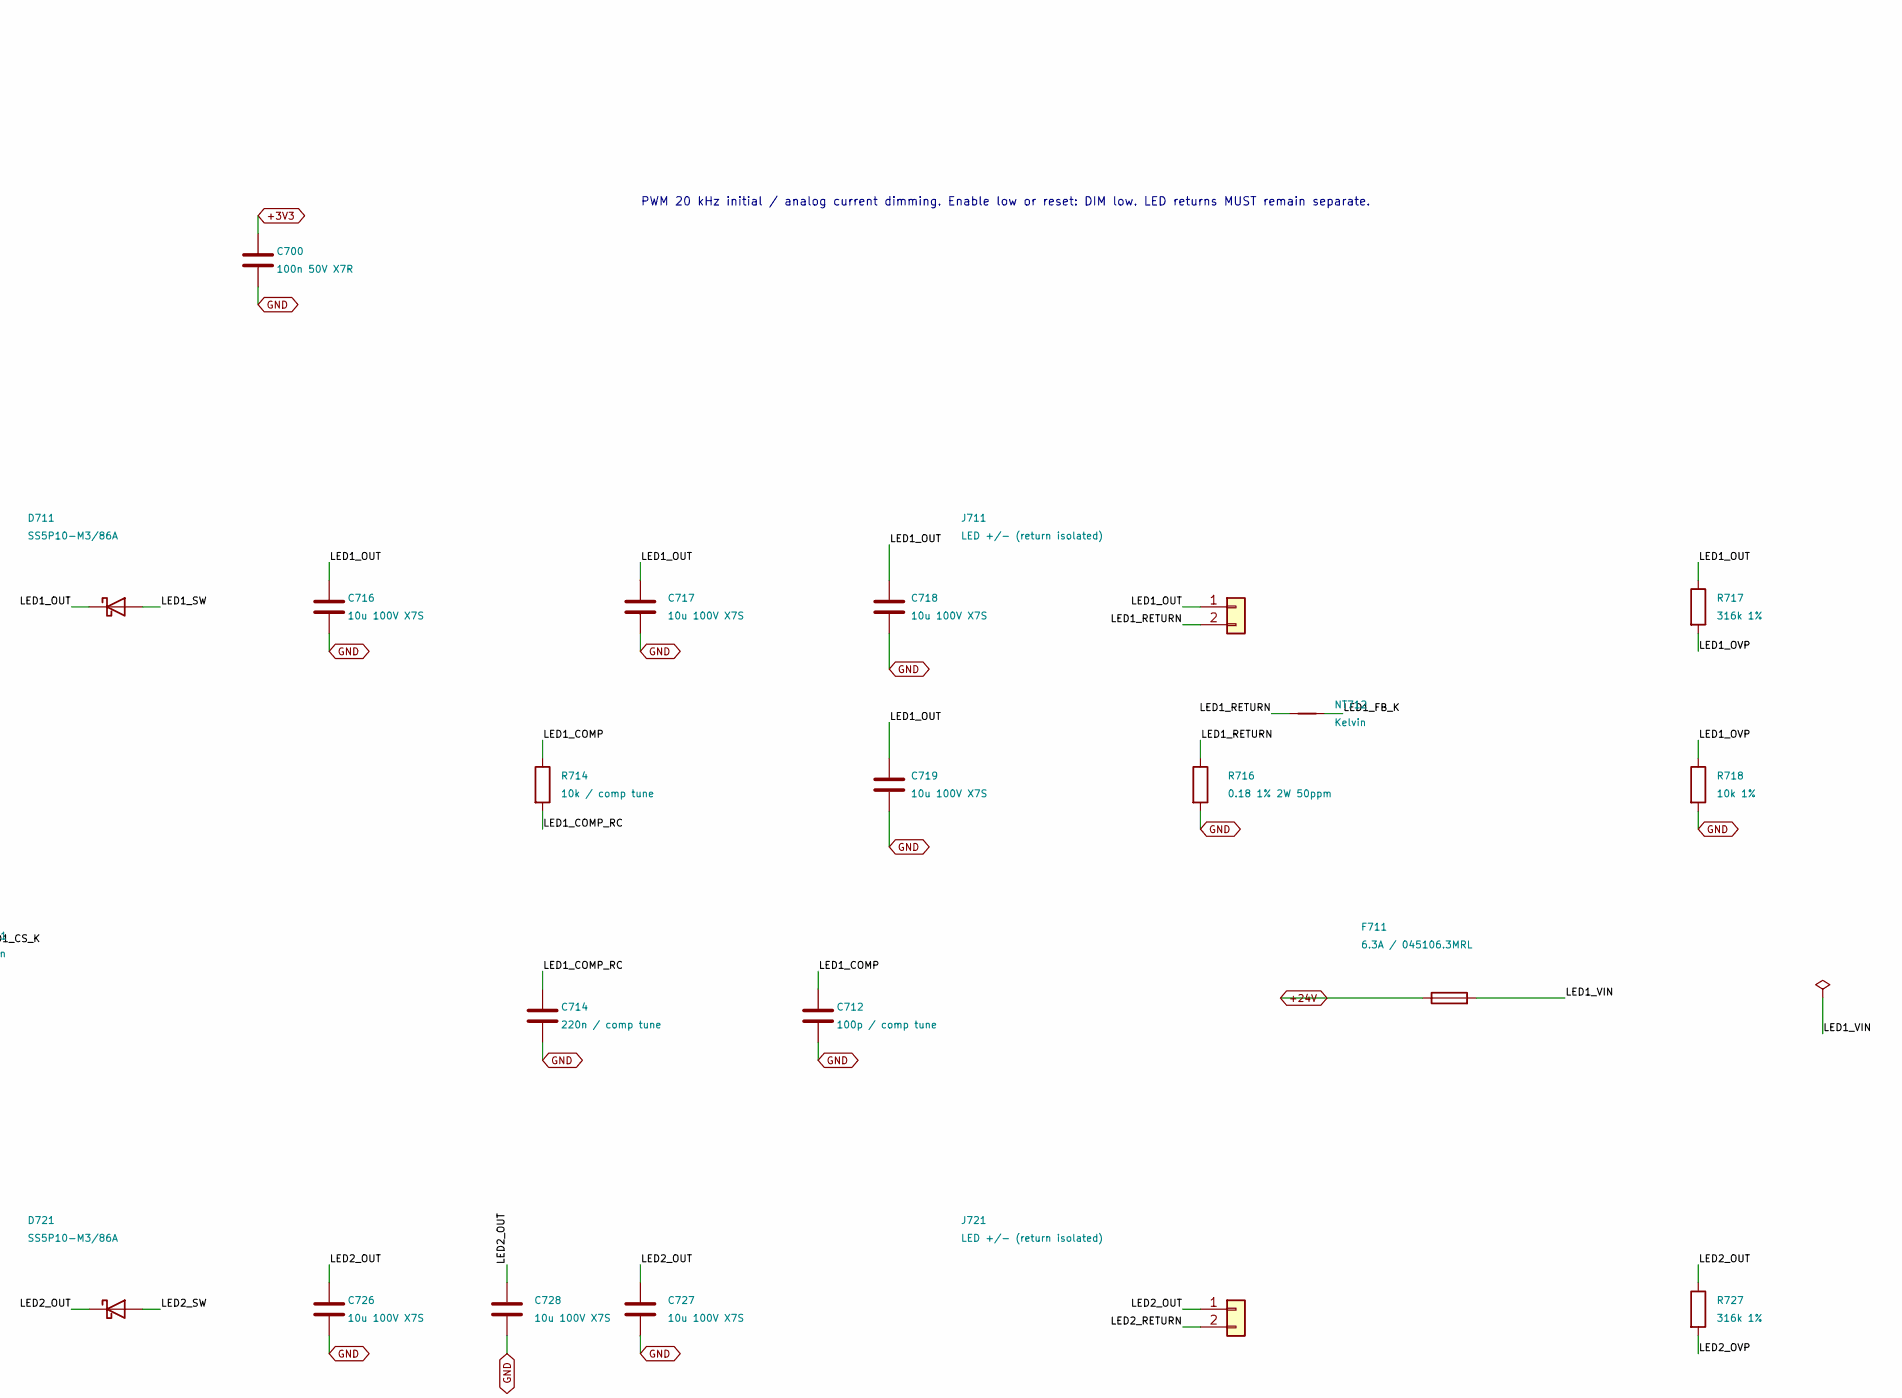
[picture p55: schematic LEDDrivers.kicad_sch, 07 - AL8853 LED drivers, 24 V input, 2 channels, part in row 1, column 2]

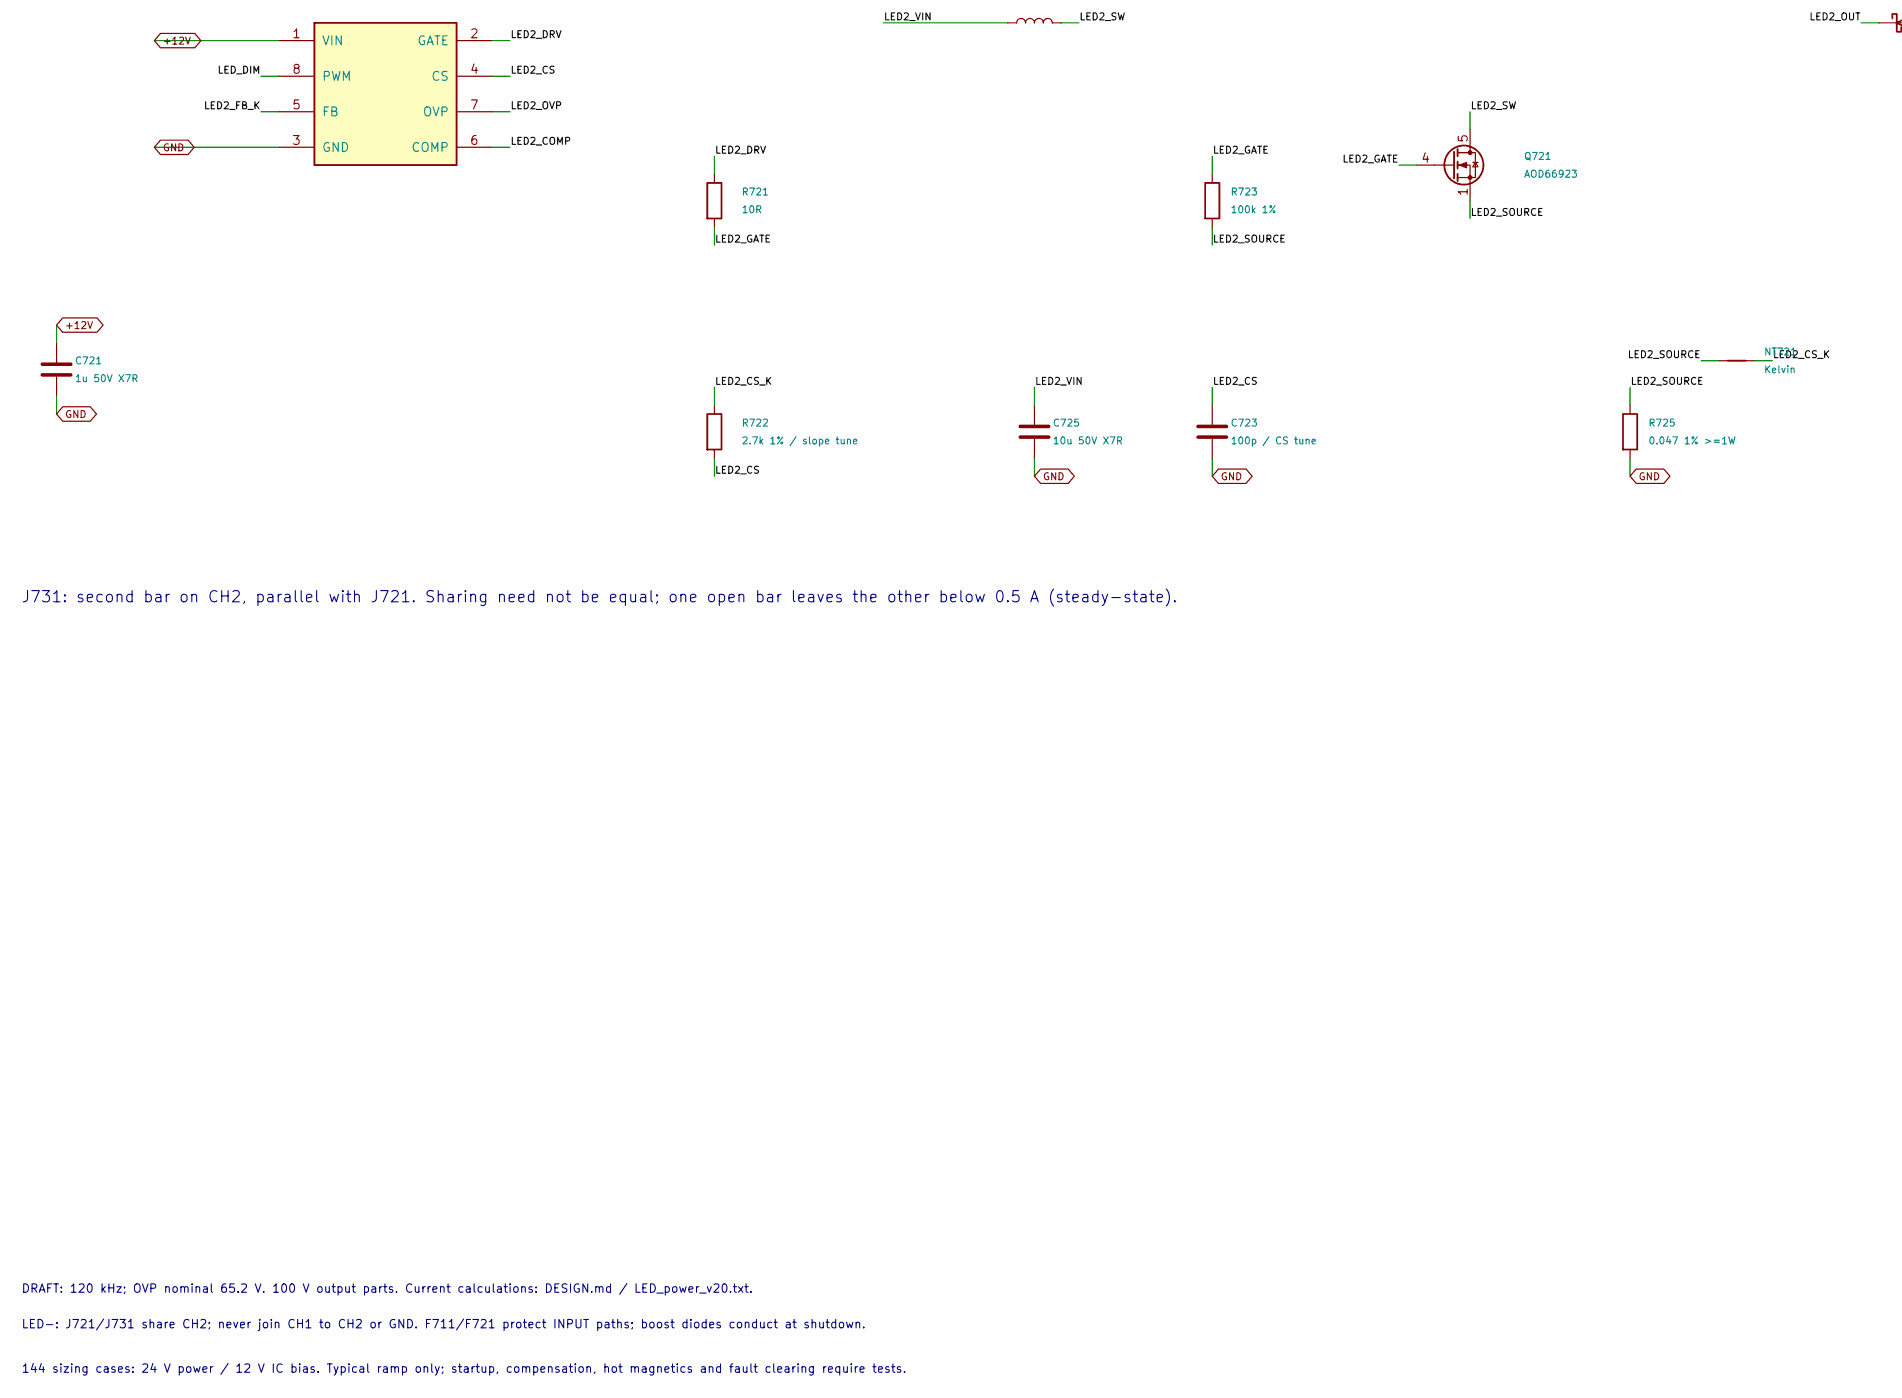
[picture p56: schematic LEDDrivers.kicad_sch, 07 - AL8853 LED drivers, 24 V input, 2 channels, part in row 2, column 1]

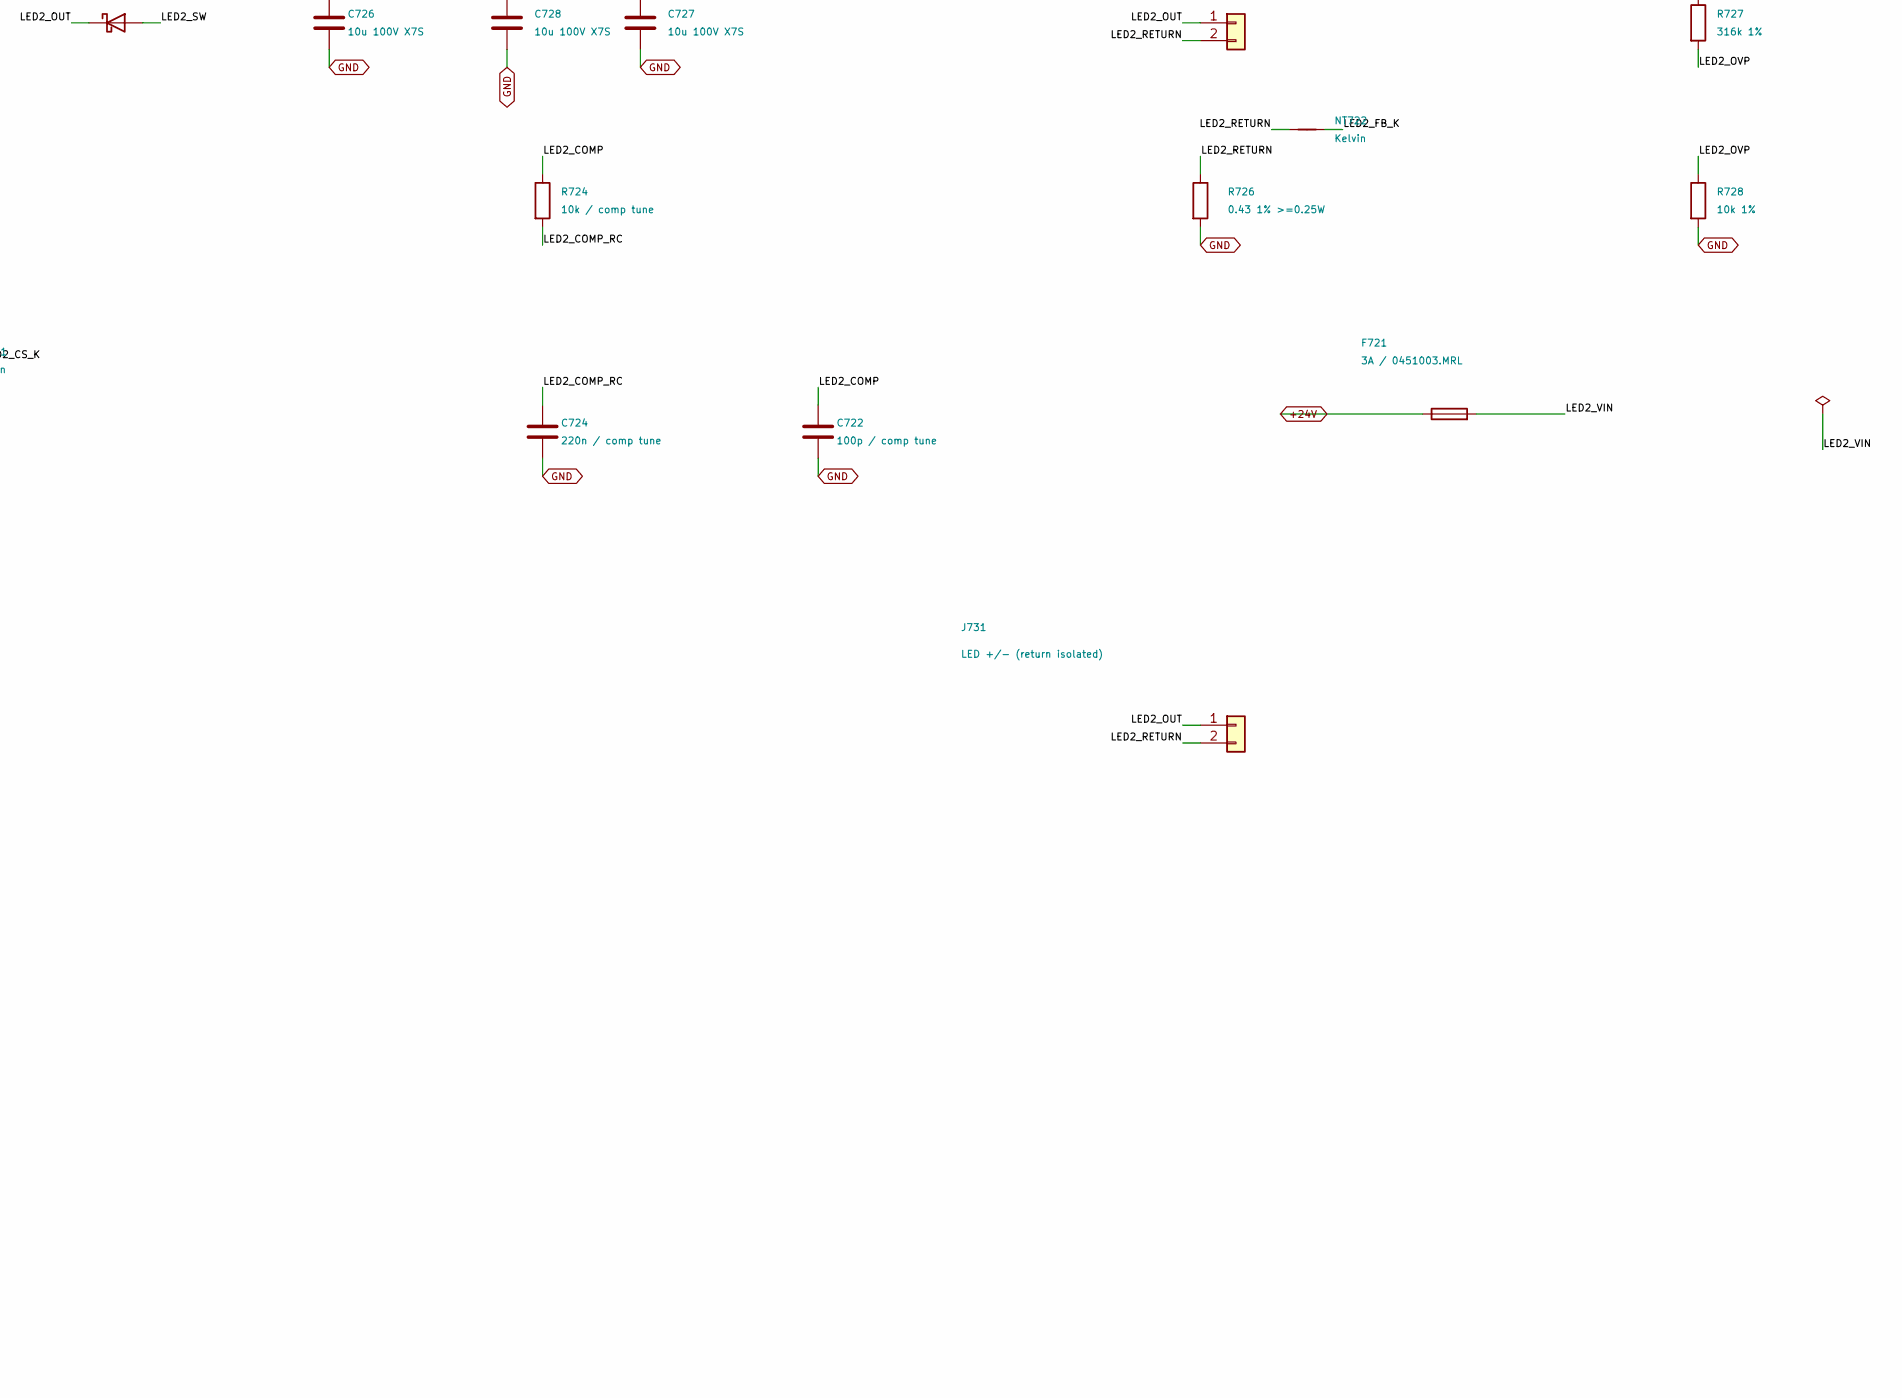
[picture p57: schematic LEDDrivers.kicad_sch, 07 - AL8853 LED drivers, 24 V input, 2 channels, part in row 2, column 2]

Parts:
C700: 100n 50V X7R; C_0603_1608Metric; MPN CL10B104KB8NNNC; LCSC C1591
C710, C715, C725: 10u 50V X7R; C_1210_3225Metric; MPN UMK325AB7106KMHP; LCSC C386166
C711, C721: 1u 50V X7R; C_0805_2012Metric; MPN CL21B105KBFNNNE; LCSC C28323
C712, C722: 100p / comp tune; C_0603_1608Metric
C713, C723: 100p / CS tune; C_0603_1608Metric
C714, C724: 220n / comp tune; C_0603_1608Metric
C716, C717, C718, C719, C726, C727, C728: 10u 100V X7S; C_1210_3225Metric; MPN GRM32EC72A106KE05L; LCSC C576517
D711, D721: SS5P10-M3/86A; Vishay_TO-277A_D_K1_A2; MPN SS5P10-M3/86A; LCSC C46986
F711: 6.3A / 045106.3MRL; Fuse_Littelfuse_451; MPN 045106.3MRL; LCSC C178982
F721: 3A / 0451003.MRL; Fuse_Littelfuse_451; MPN 0451003.MRL; LCSC C13982
J711, J721, J731: LED +/- (return isolated); TerminalBlock_KANGNEX_WJ500V-5.08_1x02_P5.08mm_Horizontal; MPN WJ500V-5.08-2P; LCSC C8465
L711: 47u SRP1770TA-470M; L_Bourns_SRP1770TA_16.9x16.9mm; MPN SRP1770TA-470M; LCSC C2041872
L721: 47u SRP1265A-470M; L_Bourns_SRP1265A; MPN SRP1265A-470M; LCSC C840530
NT711, NT712, NT721, NT722: Kelvin; NetTie-2_SMD_Pad0.5mm
Q711, Q721: AOD66923; TO-252-2_NMOS_S123_G4_D5; MPN AOD66923; LCSC C485687
R703: 47k 1%; R_0603_1608Metric; MPN RC0603FR-0747KL; LCSC C105579
R711, R721: 10R; R_0603_1608Metric
R712: 1k 1%; R_0603_1608Metric; MPN 0603WAF1001T5E; LCSC C21190
R713, R723: 100k 1%; R_0603_1608Metric; MPN 0603WAF1003T5E; LCSC C25803
R714, R724: 10k / comp tune; R_0603_1608Metric
R715: 0.027 1% >=1W; R_2512_6332Metric; MPN LR123WF270MT4E; LCSC C19633795
R716: 0.18 1% 2W 50ppm; R_2512_6332Metric; MPN FRM252WFR180TM; LCSC C48533605
R717, R727: 316k 1%; R_0603_1608Metric
R718, R728: 10k 1%; R_0603_1608Metric
R722: 2.7k 1% / slope tune; R_0603_1608Metric
R725: 0.047 1% >=1W; R_2512_6332Metric; MPN HIXD25NR047F; LCSC C52015951
R726: 0.43 1% >=0.25W; R_1206_3216Metric; MPN RLH12FTCR430; LCSC C22464907
U700: SN74LVC1G08DBVR; SOT-23-5
U710, U720: AL8853S-13; SOIC-8_3.9x4.9mm_P1.27mm

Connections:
+3V3: C700.1, U700.5 (VCC); also elsewhere on the board
+12V: C711.1, C721.1, U710.1 (VIN), U720.1 (VIN); also elsewhere on the board
+24V: C710.1, F711.1, F721.1; also elsewhere on the board
/LEDDrivers/LED1_COMP: C712.1, R714.1, U710.6 (COMP)
/LEDDrivers/LED1_COMP_RC: C714.1, R714.2
/LEDDrivers/LED1_CS: C713.1, R712.2, U710.4 (CS)
/LEDDrivers/LED1_CS_K: NT711.2, R712.1
/LEDDrivers/LED1_DRV: R711.1, U710.2 (GATE)
/LEDDrivers/LED1_FB_K: NT712.2, U710.5 (FB)
/LEDDrivers/LED1_GATE: Q711.4 (G), R711.2, R713.1
/LEDDrivers/LED1_OUT: C716.1, C717.1, C718.1, C719.1, D711.1 (K), J711.1, R717.1
/LEDDrivers/LED1_OVP: R717.2, R718.1, U710.7 (OVP)
/LEDDrivers/LED1_RETURN: J711.2, NT712.1, R716.1
/LEDDrivers/LED1_SOURCE: NT711.1, Q711.1 (S), Q711.2 (S), Q711.3 (S), R713.2, R715.1
/LEDDrivers/LED1_SW: D711.2 (A), L711.2, Q711.5 (D)
/LEDDrivers/LED1_VIN: C715.1, F711.2, L711.1
/LEDDrivers/LED2_COMP: C722.1, R724.1, U720.6 (COMP)
/LEDDrivers/LED2_COMP_RC: C724.1, R724.2
/LEDDrivers/LED2_CS: C723.1, R722.2, U720.4 (CS)
/LEDDrivers/LED2_CS_K: NT721.2, R722.1
/LEDDrivers/LED2_DRV: R721.1, U720.2 (GATE)
/LEDDrivers/LED2_FB_K: NT722.2, U720.5 (FB)
/LEDDrivers/LED2_GATE: Q721.4 (G), R721.2, R723.1
/LEDDrivers/LED2_OUT: C726.1, C727.1, C728.1, D721.1 (K), J721.1, J731.1, R727.1
/LEDDrivers/LED2_OVP: R727.2, R728.1, U720.7 (OVP)
/LEDDrivers/LED2_RETURN: J721.2, J731.2, NT722.1, R726.1
/LEDDrivers/LED2_SOURCE: NT721.1, Q721.1 (S), Q721.2 (S), Q721.3 (S), R723.2, R725.1
/LEDDrivers/LED2_SW: D721.2 (A), L721.2, Q721.5 (D)
/LEDDrivers/LED2_VIN: C725.1, F721.2, L721.1
/LEDDrivers/LED_DIM: R703.1, U700.4, U710.8 (PWM), U720.8 (PWM)
GND: C700.2, C710.2, C711.2, C712.2, C713.2, C714.2, C715.2, C716.2, C717.2, C718.2, C719.2, C721.2, C722.2, C723.2, C724.2, C725.2, C726.2, C727.2, C728.2, R703.2, R715.2, R716.2, R718.2, R725.2, R726.2, R728.2, U700.3 (GND), U710.3 (GND), U720.3 (GND); also elsewhere on the board
LIGHT_ENABLE: U700.2; also elsewhere on the board
LIGHT_PWM: U700.1; also elsewhere on the board

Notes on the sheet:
PWM 20 kHz initial / analog current dimming. Enable low or reset: DIM low. LED returns MUST remain separate.
DRAFT: 120 kHz; OVP nominal 65.2 V. 100 V output parts. Current calculations: DESIGN.md / LED_power_v20.txt.
LED-: J721/J731 share CH2; never join CH1 to CH2 or GND. F711/F721 protect INPUT paths; boost diodes conduct at shutdown.
TWO CONSTANT-CURRENT BOOST CHANNELS FROM +24V (EACH CHANNEL FUSED: F711, F721) / COMMON DIMMING
144 sizing cases: 24 V power / 12 V IC bias. Typical ramp only; startup, compensation, hot magnetics and fault clearing require tests.
CH2: 0.465 A nominal TOTAL / J721 + J731 parallel; <=0.484 A at FB/R tolerance corner
CH1: 1.111 A nominal / panel
J731: second bar on CH2, parallel with J721. Sharing need not be equal; one open bar leaves the other below 0.5 A (steady-state).
0.22 DRAFT: Q711/Q721 AOD66923 DPAK, D711/D721 SS5P10 TO-277A. Power input 24 V; AL8853 bias 12 V. CH1 back to SRP1770TA-470M / 0.027 ohm (OCP headroom). CH1 1.111 A; CH2 0.465 A total. Qualification pending.

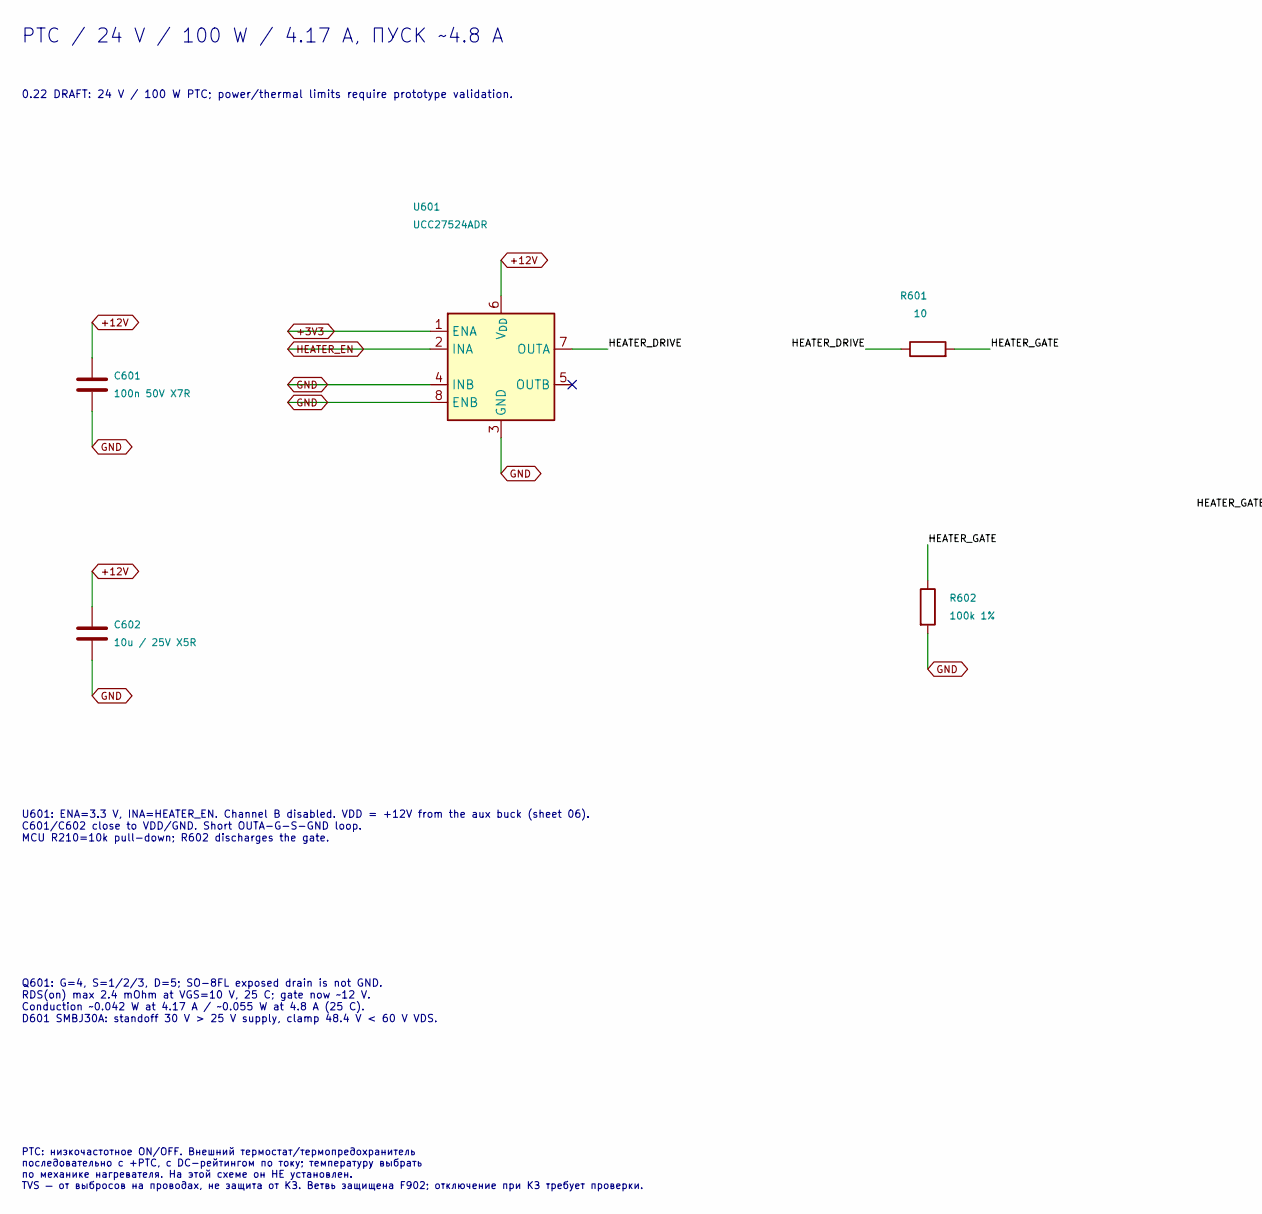
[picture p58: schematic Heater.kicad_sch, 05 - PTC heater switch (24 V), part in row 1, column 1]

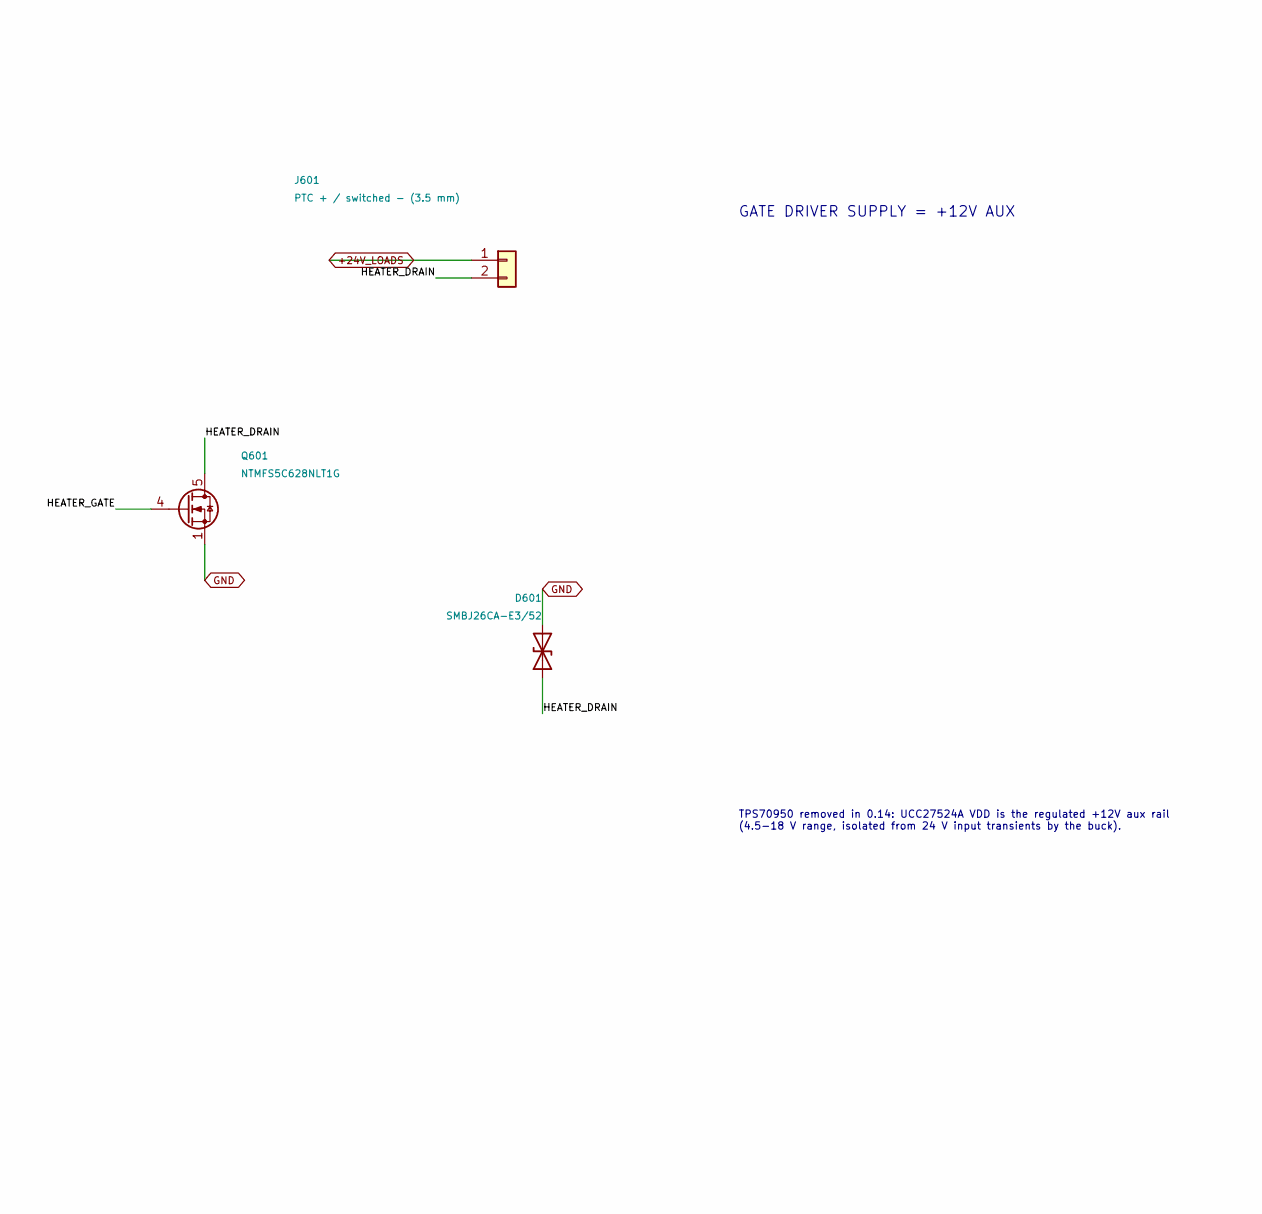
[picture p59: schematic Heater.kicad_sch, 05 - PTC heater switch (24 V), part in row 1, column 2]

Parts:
C601: 100n 50V X7R; C_0603_1608Metric; MPN CL10B104KB8NNNC; LCSC C1591
C602: 10u / 25V X5R; C_0805_2012Metric; MPN CL21A106KAYNNNE; LCSC C15850
D601: SMBJ26CA-E3/52; D_SMB; MPN SMBJ26CA-E3/52; LCSC C515606
J601: PTC + / switched - (3.5 mm); TerminalBlock_DORABO_DB125-3.5_1x02_P3.50mm_Horizontal; MPN DB125-3.5-2P-GN-S; LCSC C466970
Q601: NTMFS5C628NLT1G; ONSemi_SO-8FL_488AA; MPN NTMFS5C628NLT1G; LCSC C145537
R601: 10; R_0603_1608Metric
R602: 100k 1%; R_0603_1608Metric; MPN 0603WAF1003T5E; LCSC C25803
U601: UCC27524ADR; SOIC-8_3.9x4.9mm_P1.27mm

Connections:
+3V3: U601.1 (ENA); also elsewhere on the board
+12V: C601.1, C602.1, U601.6 (V_{DD}); also elsewhere on the board
+24V_LOADS: J601.1; also elsewhere on the board
/Outputs/Heater/HEATER_DRAIN: D601.1 (K), J601.2, Q601.5 (D)
/Outputs/Heater/HEATER_DRIVE: R601.1, U601.7 (OUTA)
/Outputs/Heater/HEATER_GATE: Q601.4 (G), R601.2, R602.1
GND: C601.2, C602.2, D601.2 (A), Q601.1 (S), Q601.2 (S), Q601.3 (S), R602.2, U601.3 (GND), U601.4 (INB), U601.8 (ENB); also elsewhere on the board
HEATER_EN: U601.2 (INA); also elsewhere on the board

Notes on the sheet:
U601: ENA=3.3 V, INA=HEATER_EN. Channel B disabled. VDD = +12V from the aux buck (sheet 06). C601/C602 close to VDD/GND. Short OUTA-G-S-GND loop. MCU R210=10k pull-down; R602 discharges the gate.
PTC: низкочастотное ON/OFF. Внешний термостат/термопредохранитель последовательно с +PTC, с DC-рейтингом по току; температуру выбрать по механике нагревателя. На этой схеме он НЕ установлен. TVS — от выбросов на проводах, не защита от КЗ. Ветвь защищена F902; отключение при КЗ требует проверки.
PTC / 24 V / 100 W / 4.17 A, ПУСК ~4.8 A
Q601: G=4, S=1/2/3, D=5; SO-8FL exposed drain is not GND. RDS(on) max 2.4 mOhm at VGS=10 V, 25 C; gate now ~12 V. Conduction ~0.042 W at 4.17 A / ~0.055 W at 4.8 A (25 C). D601 SMBJ30A: standoff 30 V > 25 V supply, clamp 48.4 V < 60 V VDS.
0.22 DRAFT: 24 V / 100 W PTC; power/thermal limits require prototype validation.
GATE DRIVER SUPPLY = +12V AUX
TPS70950 removed in 0.14: UCC27524A VDD is the regulated +12V aux rail (4.5-18 V range, isolated from 24 V input transients by the buck).

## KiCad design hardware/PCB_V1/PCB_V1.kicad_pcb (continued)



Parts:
BT301: CR2032 / NO CHARGE; BatteryHolder_MYOUNG_BS-07-A1BJ001_CR2032; MPN BS-07-A1BJ001; LCSC C2979167
C301, C303, C402: 100n 50V X7R; C_0603_1608Metric; MPN CL10B104KB8NNNC; LCSC C1591
C302: 1u / 16V; C_0603_1608Metric
C304: 18p 50V C0G; C_0603_1608Metric; MPN CL10C180JB8NNNC; LCSC C1647
C401: 22u / 10V X5R; C_0805_2012Metric; MPN CL21A226MPQNNNE; LCSC C29277
D301, D302: TPD2E2U06DCKR; SOT-323_SC-70
D303: BAV170; SOT-23; MPN BAV170; LCSC C68970
F301: PTC 0.10A / >=16V; Fuse_1206_3216Metric
J301: SHT4x / XH 2.50; JST_XH_B4B-XH-A_1x04_P2.50mm_Vertical
J302: FLOAT / 3.5 mm; TerminalBlock_DORABO_DB125-3.5_1x02_P3.50mm_Horizontal; MPN DB125-3.5-2P-GN-S; LCSC C466970
J401: HRO TF-01A; microSD_HRO_TF-01A; MPN TF-01A; LCSC C91145
R301, R302: 4.7k; R_0603_1608Metric
R303, R304, R401, R402, R403, R404: 33; R_0603_1608Metric
R305, R307: 1k 1%; R_0603_1608Metric; MPN 0603WAF1001T5E; LCSC C21190
R306, R405, R406, R407, R408, R410: 10k; R_0603_1608Metric
TP301: CLKOUT; TestPoint_Pad_D1.0mm
U301: PCF8563T/5; SOIC-8_3.9x4.9mm_P1.27mm; MPN PCF8563T/5,518; LCSC C7440
Y301: 32.768k 12.5pF; Crystal_SMD_3215-2Pin_3.2x1.5mm; MPN Q13FC13500004; LCSC C32346

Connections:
+3V3: C401.1, C402.1, D303.1 (A), F301.1, J401.4 (VDD), R301.1, R302.1, R306.1, R405.1, R406.1, R407.1, R408.1, R410.1; also elsewhere on the board
/MCU / ESP32/Peripherals/RTC_CLKOUT: TP301.1, U301.7 (SDA)
/MCU / ESP32/Peripherals/RTC_OSCI: C304.1, U301.1 (32kHz), Y301.1
/MCU / ESP32/Peripherals/RTC_OSCO: U301.2 (VCC), Y301.2
/MCU / ESP32/Peripherals/RTC_VBAT: BT301.1 (+), R307.1
/MCU / ESP32/Peripherals/RTC_VBAT_R: D303.2 (A), R307.2
/MCU / ESP32/Peripherals/RTC_VDD: C301.1, D303.3 (K), U301.8 (SCL)
/MCU / ESP32/Peripherals/SD_CS_CARD: J401.2 (DAT3/CD), R403.2, R408.2
/MCU / ESP32/Peripherals/SD_DAT1: J401.8 (DAT1), R406.2
/MCU / ESP32/Peripherals/SD_DAT2: J401.1 (DAT2), R407.2
/MCU / ESP32/Peripherals/SD_MISO_CARD: J401.7 (DAT0), R404.2, R405.2
/MCU / ESP32/Peripherals/SD_MOSI_CARD: J401.3 (CMD), R402.2, R410.2
/MCU / ESP32/Peripherals/SD_SCK_CARD: J401.5 (CLK), R401.2
/MCU / ESP32/Peripherals/SHT_3V3: C302.1, F301.2, J301.1
/MCU / ESP32/Peripherals/SHT_SCL_EXT: D301.2, J301.4, R304.2
/MCU / ESP32/Peripherals/SHT_SDA_EXT: D301.1, J301.3, R303.2
/MCU / ESP32/Peripherals/WATER_EXT: D302.1, J302.1, R305.2
GND: BT301.2 (-), C301.2, C302.2, C303.2, C304.2, C401.2, C402.2, D301.3, D302.3, J301.2, J302.2, J401.6 (VSS), J401.SH (SHIELD), U301.4 (~RST); also elsewhere on the board
I2C_SCL: R302.2, R304.1, U301.6 (VBAT); also elsewhere on the board
I2C_SDA: R301.2, R303.1, U301.5 (GND); also elsewhere on the board
SD_CS: R403.1; also elsewhere on the board
SD_MISO: R404.1; also elsewhere on the board
SD_MOSI: R402.1; also elsewhere on the board
SD_SCK: R401.1; also elsewhere on the board
WATER_LEVEL: C303.1, R305.1, R306.2; also elsewhere on the board

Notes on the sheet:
Разомкнутый вход/обрыв кабеля = нет воды. LOW ~0.30 V; фильтр + программный debounce 20..50 ms. J302: винтовая клемма 3.5 мм DORABO DB125-3.5-2P-GN-S.
04 ПОПЛАВОК / замкнут = вода есть
03 SHT4x / внешний модуль / кабель ~0.5 m
02 microSD / SPI 3.3 V
0.18: microSD ESD arrays and supply link removed. Direct +3V3; CMD/DAT0..3 retain 10k pull-ups. Handle/change the card with board power off; reduced ESD immunity. Verify 3.3 V droop during card writes; protect slot from moisture.
R401..403 у ESP32; R404 у карты.\nJ401 HRO TF-01A (push-push); DET 9 не используется; SH -> GND.\nНачальная частота SPI 4 MHz; проверка фронтов до повышения.
01 PCF8563T / I2C 0x51 / CR2032
I2C 100 kHz. Учитывать подтяжки внешнего модуля. На модуле датчика: 100n между VDD/GND. Проверить фронты на кабеле; 2.2k вместо 4.7k — только после измерения. F301: выбрать MPN и проверить падение напряжения/температуру.
SOIC-8: OSCI=1, OSCO=2, VSS=4, SDA=5, SCL=6, VDD=8; INT unused; CLKOUT -> TP301 (firmware turns it off unless RTC_CLKOUT_TRIM).\nY301 FC-135 CL 12.5 pF: OSCO has 25 pF inside (15..35), OSCI needs ~25 pF -> C304 18p + pin/stray.\nTrim C304 on the prototype by the 32.768 kHz CLKOUT frequency after po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
0.22 DRAFT — схема для проверки; разводка и испытания ещё не выполнены.
ПЕРИФЕРИЯ / RTC + microSD + ВНЕШНИЕ ДАТЧИКИ


Board: 4 copper layers, 100.0 x 100.0 mm, 170 parts (1 on the bottom side), 94 nets.

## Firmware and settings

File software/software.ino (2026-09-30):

#include <esp_task_wdt.h>
#include <Arduino.h>
#include <stdarg.h>
#include <stddef.h>
#include <Wire.h>
#include <SPI.h>
#include <SD.h>
#include <SPIFFS.h>
#include <RTClib.h>
#include <Adafruit_SHT4x.h>
#include <WiFi.h>
#include <ESPAsyncWebServer.h>
#include <Preferences.h>
#include <HTTPClient.h>
#include <WiFiClientSecure.h>
#include <vector>
#include <atomic>
#include <esp_random.h>
#include <time.h>
#include "Safety.h"
#include "SafetyTests.h"
#include "UbidotsCA.h"

// --- Настройки подключения к домашнему роутеру и Ubidots ---
// Значения по умолчанию используются только при первой прошивке / если NVS пуст.
// Реальные значения хранятся в Preferences и редактируются на вкладке "WiFi / Ubidots".
#define DEFAULT_WIFI_SSID ""
#define DEFAULT_WIFI_PASS ""
#define DEFAULT_UBIDOTS_TOKEN ""
#define DEFAULT_DEVICE_LABEL  "kireal"
#define DEFAULT_AP_SSID       "KiReal"
#define DEFAULT_AP_PASS ""

String admin_password; // Immutable after setup, never returned through HTTP.
String csrf_token;

// --- Распиновка периферии ---
#define SD_CS_PIN     5
#define LED_PWM_PIN   4
#define FAN1_PWM_PIN  13
#define FAN2_PWM_PIN  33
#define PUMP_PIN      25 // реле/мосфет насоса полива — при необходимости смени на свободный GPIO
#define HEATER_PIN    27 // реле обогревателя — при необходимости смени на свободный GPIO
#define I2C_SDA_PIN   21 // Стандартные пины I2C для ESP32 (то, что использует Wire.begin() без аргументов)
#define I2C_SCL_PIN   22
#define WATER_LEVEL_PIN 32 // Датчик уровня воды в баке (свободный GPIO, не занят другой периферией)

#define PWM_FREQ      5000
#define PWM_RES       8

// --- Ограничения длины строковых настроек ---
#define WIFI_SSID_MAX 32   // стандарт 802.11
#define WIFI_PASS_MAX 63   // WPA2
#define TOKEN_MAX     128
#define LABEL_MAX     64

// =====================================================================================
// ДАННЫЕ ПРОШИВКИ: НАСТРОЙКИ И СОСТОЯНИЕ
// =====================================================================================
// Раньше это были ~50 отдельных глобальных переменных, которые три задачи на двух ядрах
// (loop, веб-сервер, Ubidots) читали и писали кто как, — отсюда была большая часть гонок.
// Теперь правило одно:
//   * Settings — то, что задал пользователь. Меняет только обработчик /save-settings:
//     разбирает форму в свою копию и публикует её целиком (publishSettings()).
//     Все остальные работают со своей копией (settingsSnapshot()).
//   * State — то, что происходит сейчас. Пишет только loop() в рабочую копию `state`
//     и публикует её (publishState()); веб и Ubidots читают stateSnapshot().
// Обе структуры — простые данные без String и указателей, поэтому копируются одним memcpy
// под спинлоком: без аллокаций, без таймаутов и без 503 на ровном месте.
//
// Типы объявлены до первой функции файла намеренно: Arduino IDE вставляет свои
// автоматические прототипы функций именно туда, и типы из их сигнатур должны быть известны.

struct Settings {
  // Климат
  float temp_target;        // Целевая температура дня, °C (от неё считаются лампа и вентиляторы)
  float temp_delta;         // Полуширина рабочего диапазона и гистерезис обогрева, °C
  float temp_target_night;  // Цель обогревателя ночью, °C (гистерезис temp_delta общий)
  float min_hum_night;      // Ночью ниже этой влажности вентиляторы держат минимум, %
  float max_hum_night;      // ...а выше этой — максимум, %

  // Свет
  int led_on_hour, led_on_minute;
  int led_off_hour, led_off_minute;
  int led_min_limit, led_max_limit;              // Мощность лампы днём, %

  // Вентиляция
  int fan1_min_limit, fan1_max_limit;            // Днём, по температуре, %
  int fan2_min_limit, fan2_max_limit;
  int fan_night_min_limit, fan_night_max_limit;  // Ночью, обоими вентиляторами по влажности, %

  // Обогрев: 0 = только день, 1 = только ночь, 2 = всегда, 3 = никогда
  int heater_mode;

  // Автополив
  uint8_t watering_days;       // Битовая маска: бит0=Пн, бит1=Вт, ... бит6=Вс
  int watering_hour, watering_minute;
  int watering_duration_sec;
  bool water_sensor_enabled;   // Учитывать ли датчик уровня воды перед стартом/во время полива

  uint32_t start_timestamp;    // Начало цикла выращивания (unixtime), 0 = цикл не начат

  // Сеть и облако
  char wifi_ssid[WIFI_SSID_MAX + 1];
  char wifi_pass[WIFI_PASS_MAX + 1];
  char ubidots_token[TOKEN_MAX + 1];
  char device_label[LABEL_MAX + 1];
  char ap_ssid[WIFI_SSID_MAX + 1];   // Точка доступа платы — к ней подключается телефон/ноутбук
  char ap_pass[WIFI_PASS_MAX + 1];   // WPA2 only; empty form means keep existing password
};

struct State {
  float temp;           // Последнее валидное показание SHT4x, °C
  float hum;            // ...и влажности, %
  int led_pwm;          // Текущий ШИМ, 0-255
  int fan1_pwm;
  int fan2_pwm;
  bool is_day;
  bool sht_online;
  bool rtc_online;
  bool clock_trusted;
  bool pump_active;
  bool heater_active;
};

// Описание одной настройки для таблицы SETTING_DEFS (см. ниже)
enum SettingType : uint8_t { ST_FLOAT, ST_INT, ST_U8, ST_BOOL, ST_U32, ST_STRING };

enum SettingFlags : uint8_t {
  SF_SECRET  = 1 << 0,  // Наружу не отдаётся (только <param>_set), пустое поле формы = "не менять"
  SF_TRIM    = 1 << 1,  // Обрезать пробелы по краям
  SF_NO_FORM = 1 << 2,  // Из формы автоматически не разбирается (для поля есть особый обработчик)
};

struct SettingDef {
  const char *param;     // Имя поля в форме и в JSON /api/settings
  const char *nvsKey;    // Ключ в NVS (до 15 символов!) — исторически не везде совпадает с param
  SettingType type;
  uint16_t offset;       // Где поле лежит внутри Settings
  uint16_t size;         // Его размер (для строк — размер буфера)
  float lo, hi;          // Числа: диапазон клэмпа. Строки: допустимая длина непустого значения
  float def;             // Значение по умолчанию для чисел
  const char *defStr;    // ...и для строк
  uint8_t flags;
  const char *errGroup;  // Строки: какой баннер ошибки показать на странице, если значение отклонено
};

// Рабочая копия состояния. Трогает ТОЛЬКО loop() (и setup() до старта остальных задач)
State state = {};

// Опубликованные копии для остальных задач — доступ только через функции ниже
static State stateShared = {};
static portMUX_TYPE stateMux = portMUX_INITIALIZER_UNLOCKED;
static Settings settingsShared = {};
static portMUX_TYPE settingsMux = portMUX_INITIALIZER_UNLOCKED;

// --- Кольцевой буфер для показа Serial.print()-сообщений на веб-странице (/api/console) ---
#define LOG_BUFFER_SIZE 4096
static char logBuffer[LOG_BUFFER_SIZE];
static volatile size_t logHead = 0;
static volatile bool logWrapped = false;
static portMUX_TYPE logMux = portMUX_INITIALIZER_UNLOCKED;

void logRaw(const char *data, size_t len) {
  portENTER_CRITICAL(&logMux);
  for (size_t i = 0; i < len; i++) {
    logBuffer[logHead] = data[i];
    logHead = (logHead + 1) % LOG_BUFFER_SIZE;
    if (logHead == 0) logWrapped = true;
  }
  portEXIT_CRITICAL(&logMux);
}

// Замена logPrintln()/logPrintf() — пишет и на аппаратный UART, и в буфер для веба.
// Core 0 (задача Ubidots) и Core 1 (loop/setup) могут писать одновременно, поэтому буфер
// защищён спинлоком (portENTER_CRITICAL), а не мьютексом — запись короткая и частая.
void logPrintln(const String &msg) {
  Serial.println(msg);
  String line = msg + "\n";
  logRaw(line.c_str(), line.length());
}

void logPrintf(const char *fmt, ...) {
  char buf[192];
  va_list args;
  va_start(args, fmt);
  vsnprintf(buf, sizeof(buf), fmt, args);
  va_end(args);
  Serial.print(buf);
  logRaw(buf, strlen(buf));
}

// Возвращает содержимое буфера в правильном хронологическом порядке одной строкой.
// Под спинлоком делаем ТОЛЬКО memcpy: собирать String (а значит, дёргать кучу) с
// выключенными прерываниями нельзя — на 4 КБ это тысячи реаллокаций и реальный риск
// паники/срыва watchdog, а страница дёргает /api/console каждые 3 секунды.
// Буфер статический (4 КБ на стеке async-задачи не поместятся); обработчики
// AsyncWebServer выполняются последовательно в одной задаче, поэтому гонки за него нет.
String getLogSnapshot() {
  static char snapshotCopy[LOG_BUFFER_SIZE + 1];
  size_t len;

  portENTER_CRITICAL(&logMux);
  size_t head = logHead;
  bool wrapped = logWrapped;
  if (!wrapped) {
    memcpy(snapshotCopy, logBuffer, head);
    len = head;
  } else {
    size_t tailLen = LOG_BUFFER_SIZE - head;
    memcpy(snapshotCopy, logBuffer + head, tailLen);
    memcpy(snapshotCopy + tailLen, logBuffer, head);
    len = LOG_BUFFER_SIZE;
  }
  portEXIT_CRITICAL(&logMux);

  snapshotCopy[len] = 0;
  return String(snapshotCopy);
}

// Экранирование строки для безопасной вставки в JSON: имена файлов SD, а также SSID,
// имя устройства и прочее, что вводит пользователь (одна кавычка ломала разбор на странице)
String jsonEscape(const char* s) {
  String out;
  for (int i = 0; s[i] != '\0'; i++) {
    char c = s[i];
    if (c == '"' || c == '\\') { out += '\\'; out += c; }
    else if (c == '\n' || c == '\r' || c == '\t') { out += ' '; }
    else if ((uint8_t)c < 0x20) { /* прочие control-символы пропускаем */ }
    else out += c;
  }
  return out;
}

// uint64_t -> String: обычный String(uint64_t) в Arduino не поддерживается,
// а SD.totalBytes()/usedBytes() возвращают именно uint64_t
String u64str(uint64_t v) {
  if (v == 0) return "0";
  char buf[21];
  int i = 20;
  buf[i] = '\0';
  while (v > 0 && i > 0) { buf[--i] = '0' + (char)(v % 10); v /= 10; }
  return String(&buf[i]);
}

// Удаляет из корня SD только файлы логов (*.csv). Раньше здесь был рекурсивный
// wipePath("/"), который сносил вообще всё содержимое карты — включая файлы, не имеющие
// к логам отношения. Сначала собираем список, потом удаляем: удалять во время обхода
// каталога нельзя, это ломает итератор FatFS.
int clearCsvLogs() {
  int removed = 0;
  std::vector<String> victims;

  File dir = SD.open("/");
  if (!dir) return 0;
  if (!dir.isDirectory()) { dir.close(); return 0; }

  File entry = dir.openNextFile();
  while (entry) {
    if (!entry.isDirectory()) {
      String full = String(entry.path()); // абсолютный путь (ESP32 core 3.x)
      String lower = full;
      lower.toLowerCase();
      if (lower.endsWith(".csv")) victims.push_back(full);
    }
    entry.close();
    entry = dir.openNextFile();
  }
  dir.close();

  for (size_t i = 0; i < victims.size(); i++) {
    if (SD.remove(victims[i])) removed++;
  }
  return removed;
}

// --- Внутреннее состояние loop(): никто, кроме loop() и setup(), эти переменные не трогает ---
uint32_t pump_start_ms = 0;   // Отсчёт длительности полива по millis(), а не по RTC
uint32_t pump_duration_ms = 0;
uint32_t last_watering_day = 0;    // Защита от повторного срабатывания в тот же день (хранится в NVS)

unsigned long last_sht_retry = 0;                  // Когда последний раз пытались восстановить датчик
const unsigned long SHT_RETRY_INTERVAL_MS = 30000; // Пауза между попытками восстановления, мс
int sht_recovery_streak = 0;                       // Счётчик подряд успешных попыток восстановления
unsigned long last_emergency_log_ms = 0;           // Когда последний раз писали в консоль про аварийный режим (0 = ещё не писали)
const int SHT_RECOVERY_STREAK_NEEDED = 3;          // Сколько подряд удачных попыток нужно, чтобы снова доверять датчику
unsigned long last_rtc_retry = 0;                  // Когда последний раз пытались восстановить RTC
const unsigned long RTC_RETRY_INTERVAL_MS = 30000; // Пауза между попытками восстановления, мс
int rtc_recovery_streak = 0;                       // Счётчик подряд успешных попыток восстановления
const int RTC_RECOVERY_STREAK_NEEDED = 3;          // Сколько подряд удачных попыток нужно, чтобы снова доверять RTC

// Переменные для программного дублирования времени (на случай отказа RTC)
uint32_t backup_unixtime = 1774838400; // Дефолтный 2026 год, если RTC умер сразу при старте
uint32_t last_rtc_check_ms = 0;

// Время и запросы к RTC трогает только loop(). Веб-обработчики крутятся в задаче
// AsyncWebServer (другое ядро): раньше они звали getSafeDateTime() и rtcAdjust() напрямую,
// то есть лезли в I2C параллельно с опросом SHT4x и одновременно правили rtc_online/backup_unixtime.
std::atomic<uint32_t> cached_unixtime{0};  // Снимок времени для веб-обработчиков, обновляет loop()
std::atomic<uint32_t> pending_time_set{0}; // Запрос "выставить часы" с формы; применяет loop()

// --- Хендлы FreeRTOS для многоядерности ---
TaskHandle_t UbidotsTaskHandle = NULL;

// --- Инициализация объектов ---
Adafruit_SHT4x sht40 = Adafruit_SHT4x();
// Плата v0.20: NXP PCF8563 (0x51). Готовый модуль DS3231 (0x68) на стенде тоже поддерживается:
// микросхема определяется при каждом rtcBegin(), регистры читаются напрямую (readRTC()).
enum class RtcChip : uint8_t { None, Pcf8563, Ds3231 };
RTC_PCF8563 pcf8563;
RTC_DS3231 ds3231;
RtcChip rtc_chip = RtcChip::None;
AsyncWebServer server(80);
Preferences preferences;

// --- Хелперы валидации входных данных (защита от некорректных значений из веб-формы) ---
int clampInt(int v, int lo, int hi) {
  if (v < lo) return lo;
  if (v > hi) return hi;
  return v;
}

float clampFloat(float v, float lo, float hi) {
  if (v < lo) return lo;
  if (v > hi) return hi;
  return v;
}
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
void loop() {
  static unsigned long lastClimateTime = 0;
  unsigned long currentMillis = millis();
  if (state.pump_active && elapsedMs(currentMillis, pump_start_ms) >= pump_duration_ms) {
    state.pump_active = false;
    digitalWrite(PUMP_PIN, LOW);
    logPrintln("[Watering] Pump stopped at deadline.");
  }
  tryRecoverRTC(currentMillis); // Не блокирует: сам ограничивает частоту попыток внутри

  // Время читаем раз в секунду, а не на каждой итерации loop(): rtc.now() — полноценная
  // транзакция по I2C, и раньше она крутилась тысячи раз в секунду на той же шине,
  // по которой опрашивается SHT4x. Там же обновляем свою копию настроек: изменения из
  // веба вступают в силу не позже чем через секунду, а весь цикл видит одну цельную версию.
  static DateTime now((uint32_t)0);
  static Settings cfg;
  static unsigned long lastTimeRead = 0;
  if (lastTimeRead == 0 || currentMillis - lastTimeRead >= 1000) {
    lastTimeRead = currentMillis;
    now = getSafeDateTime();
    cached_unixtime = now.unixtime(); // Снимок, который отдают веб-обработчики
    cfg = settingsSnapshot();
  }

  // Часы, выставленные из веб-формы, применяем здесь: в I2C ходит только loop()
  uint32_t requested = pending_time_set.exchange(0);
  if (requested != 0) {
    DateTime userTime(requested);
    state.rtc_online = false;
    if (rtcBegin()) {
      rtcAdjust(userTime);
      DateTime checked;
      state.rtc_online = readRTC(checked) && checked.unixtime() >= requested && checked.unixtime() - requested <= 2;
    }
    state.clock_trusted = true;
    rtc_recovery_streak = 0;
    backup_unixtime = requested;
    last_rtc_check_ms = millis();
    now = userTime;
    cached_unixtime = requested;
    logPrintln("[RTC] Часы выставлены вручную через веб-интерфейс");
  }

  if (currentMillis - lastClimateTime >= 10000) {
    lastClimateTime = currentMillis;

    int current_hour = now.hour();
    int current_minutes = current_hour * 60 + now.minute();
    int on_minutes = cfg.led_on_hour * 60 + cfg.led_on_minute;
    int off_minutes = cfg.led_off_hour * 60 + cfg.led_off_minute;

    if (on_minutes == off_minutes) state.is_day = true; // время включения == времени выключения — считаем "весь день"
    else if (on_minutes < off_minutes) state.is_day = (current_minutes >= on_minutes && current_minutes < off_minutes);
    else state.is_day = (current_minutes >= on_minutes || current_minutes < off_minutes);
    const bool is_day = state.is_day;

    int pwm_fan1_min = map(cfg.fan1_min_limit, 0, 100, 0, 255);
    int pwm_fan1_max = map(cfg.fan1_max_limit, 0, 100, 0, 255);
    int pwm_fan2_min = map(cfg.fan2_min_limit, 0, 100, 0, 255);
    int pwm_fan2_max = map(cfg.fan2_max_limit, 0, 100, 0, 255);
    int pwm_led_min = map(cfg.led_min_limit, 0, 100, 0, 255);
    int pwm_led_max = map(cfg.led_max_limit, 0, 100, 0, 255);
    int pwm_fan_night_min = map(cfg.fan_night_min_limit, 0, 100, 0, 255);
    int pwm_fan_night_max = map(cfg.fan_night_max_limit, 0, 100, 0, 255);

    int target_led, target_fan1, target_fan2;
    float read_temp = state.temp; // По умолчанию — последнее известное валидное значение, а не 0.0
    float read_hum = state.hum;

    // Чтение датчика с проверкой на ошибку
    sensors_event_t humidity, temp;
    if (state.sht_online) {
      if (sht40.getEvent(&humidity, &temp)) {
        read_temp = temp.temperature;
        read_hum = humidity.relative_humidity;

        // Защита от "зависших" нереалистичных данных (за пределами работы датчика)
        if (read_temp < -20.0 || read_temp > 80.0 || read_hum < 0.0 || read_hum > 100.0) {
          state.sht_online = false;
          logPrintf("[SHT4x] Показания вне рабочего диапазона: T=%.2f RH=%.2f\n", read_temp, read_hum);
        }
      } else {
        state.sht_online = false;
        logPrintln("[SHT4x] Датчик перестал отвечать (getEvent вернул ошибку).");
      }
      if (!state.sht_online) {
        // Причину пишем один раз, в момент отказа, — дальше её подтверждают попытки восстановления
        logSht4xDiagnosis();
        logI2CScan();
      }
    }

    // Датчик офлайн — периодически пробуем восстановиться, не дожидаясь перезагрузки платы.
    // Нужно несколько (SHT_RECOVERY_STREAK_NEEDED) подряд успешных попыток с интервалом
    // SHT_RETRY_INTERVAL_MS, прежде чем снова начать доверять показаниям.
    if (!state.sht_online && (currentMillis - last_sht_retry >= SHT_RETRY_INTERVAL_MS)) {
      last_sht_retry = currentMillis;
      recoverI2CBus(); // Освобождаем шину на случай, если она физически "залипла"
      sensors_event_t retryHumidity, retryTemp;
      bool retry_ok = sht40.begin() && sht40.getEvent(&retryHumidity, &retryTemp) &&
                       retryTemp.temperature >= -20.0 && retryTemp.temperature <= 80.0 &&
                       retryHumidity.relative_humidity >= 0.0 && retryHumidity.relative_humidity <= 100.0;

      if (retry_ok) {
        sht_recovery_streak++;
        logPrintf("[SHT4x] Попытка восстановления %d/%d успешна\n", sht_recovery_streak, SHT_RECOVERY_STREAK_NEEDED);
        if (sht_recovery_streak >= SHT_RECOVERY_STREAK_NEEDED) {
          state.sht_online = true;
          read_temp = retryTemp.temperature;
          read_hum = retryHumidity.relative_humidity;
          sht_recovery_streak = 0;
          last_emergency_log_ms = 0; // Следующий отказ снова будет залогирован сразу
          logPrintln("[SHT4x] Датчик восстановлен, выходим из аварийного режима.");
        }
      } else {
        sht_recovery_streak = 0; // Сбрасываем счётчик серии при любой неудачной попытке
        logSht4xDiagnosis();     // Раз в 30 секунд — на каком шаге датчик по-прежнему не отвечает
      }
    }

    // ЛОГИКА АВАРИЙНОГО РЕЖИМА ИЛИ НОРМАЛЬНОЙ РАБОТЫ
    if (!state.sht_online) {
      // --- АВАРИЯ: Датчик сломан. Включаем безопасный пресет ---
      // Вентиляторы на 50% выбранного диапазона (день — температурный диапазон, ночь — ночной диапазон)
      if (is_day) {
        target_fan1 = map(50, 0, 100, pwm_fan1_min, pwm_fan1_max);
        target_fan2 = map(50, 0, 100, pwm_fan2_min, pwm_fan2_max);
      } else {
        target_fan1 = map(50, 0, 100, pwm_fan_night_min, pwm_fan_night_max);
        target_fan2 = target_fan1;
      }
      // Светильник на минимальный уровень дня, чтобы не сжечь растения светом/жаром
      target_led = is_day ? pwm_led_min : 0;

      // Датчик недоступен — не доверяем показаниям, обогрев выключаем из соображений безопасности
      state.heater_active = false;
      digitalWrite(HEATER_PIN, LOW);

      // Раньше эта строка писалась каждые 10 секунд и за пару минут вытесняла из 4-килобайтной
      // веб-консоли всё остальное — включая сообщения о том, почему датчик отказал
      if (last_emergency_log_ms == 0 || currentMillis - last_emergency_log_ms >= 300000) {
        last_emergency_log_ms = currentMillis;
        logPrintln("[АВАРИЙНЫЙ РЕЖИМ]: Отказ SHT4x! Климат зафиксирован на безопасных уровнях.");
      }
    }
    else {
      // --- НОРМАЛЬНАЯ РАБОТА ---
      // Защита от temp_delta == 0, чтобы map() не делил на ноль
      float safe_delta = max(cfg.temp_delta, 0.1f);
      float current_min = cfg.temp_target - safe_delta;
      float current_max = cfg.temp_target + safe_delta;

      // Обогрев: своя цель ночью (temp_target_night), днём — общая temp_target.
      // На вентиляторы/лампу (current_min/current_max выше) это не влияет — они всегда считаются от дневной temp_target.
      float heater_target = is_day ? cfg.temp_target : cfg.temp_target_night;
      float heater_min = heater_target - safe_delta;

      bool heater_schedule_ok = (cfg.heater_mode == 2) || (cfg.heater_mode == 0 && is_day) || (cfg.heater_mode == 1 && !is_day);
      if (!heater_schedule_ok) {
        state.heater_active = false;
      } else if (!state.heater_active && read_temp <= heater_min) {
        state.heater_active = true;
      } else if (state.heater_active && read_temp >= heater_target) {
        state.heater_active = false;
      }
      digitalWrite(HEATER_PIN, state.heater_active ? HIGH : LOW);

      if (read_temp <= current_min) {
        target_led = is_day ? pwm_led_max : 0;
        target_fan1 = pwm_fan1_min;
        target_fan2 = pwm_fan2_min;
      }
      else if (read_temp >= current_max) {
        target_led = is_day ? pwm_led_min : 0;
        target_fan1 = pwm_fan1_max;
        target_fan2 = pwm_fan2_max;
      }
      else {
        target_led = is_day ? map(read_temp * 100, current_min * 100, current_max * 100, pwm_led_max, pwm_led_min) : 0;
        target_fan1 = map(read_temp * 100, current_min * 100, current_max * 100, pwm_fan1_min, pwm_fan1_max);
        target_fan2 = map(read_temp * 100, current_min * 100, current_max * 100, pwm_fan2_min, pwm_fan2_max);
      }
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

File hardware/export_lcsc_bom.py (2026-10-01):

"""Export the order BOM for LCSC from the schematic and the dated price snapshots.

  python export_lcsc_bom.py netlist.xml PCB_V1/price_snapshot_v22.json PCB_V1/jlc_snapshot_v22.json OUTDIR [--rev v22] [--boards 1] [--spare-rate 0]

Writes into OUTDIR (all deterministic: same inputs give the same bytes):
  BOM_LCSC_<rev>.csv / .xlsx   upload file for https://www.lcsc.com/bom (.csv/.xlsx, up to 800 lines): Quantity,
                               LCSC Part Number, Manufacturer Part Number, Manufacturer, Description, Customer Part Number
                               (the designators). Only parts LCSC can supply at the snapshot date. Quantity is the
                               number of parts for --boards boards (default one): the BOM quantity, not rounded to
                               the LCSC minimum order. The workbook also has the full BOM, the parts to buy elsewhere
                               and the totals.
  BOM_PCB_V1_<rev>.csv         full grouped BOM: one line per purchasing code, with package, mounting, price tiers
                               applied, stock, JLCPCB library class, notes; not fitted lines and extras included.

Quantities: parts per board x boards (plus --spare-rate of that, at least one piece, when given). The full BOM also
shows the LCSC minimum and multiple and the order for 1 and for 5 boards rounded up to them, with the list price tier
at that order quantity (the cost columns and totals use these rounded orders). Prices, stock and minimums are the snapshot of the dates in the snapshot file, not a live quote: the LCSC
BOM tool shows the live values after upload and the quantities can be edited there.
"""
import argparse
import csv
import json
import math
import re
import sys
import xml.etree.ElementTree as ET
import zipfile
from collections import Counter
from decimal import Decimal
from pathlib import Path
from xml.sax.saxutils import escape

import audit_bom_cost as audit

CATEGORY = {'U': 'IC / module', 'Q': 'Transistor / MOSFET', 'D': 'Diode / TVS / ESD', 'L': 'Inductor', 'C': 'Capacitor',
            'R': 'Resistor', 'F': 'Fuse / holder', 'J': 'Connector', 'SW': 'Switch', 'BT': 'Battery holder', 'Y': 'Crystal',
            'NT': 'Net tie (copper only)', 'TP': 'Test pad (copper only)'}
THT = ('Connector_JST', 'PinHeader', 'AMASS_XT60', 'BatteryHolder', 'TerminalBlock', 'Fuseholder_Blade')
PART_TYPE = {'mpn': 'Exact MPN', 'generic': 'Equivalent allowed', 'clone': 'Second source', 'option': 'Pending decision',
             'extra': 'Extra, not on schematic', 'zero': 'Not fitted'}
JLC_CLASS = {'B': 'Basic', 'E': 'Extended', 'P': 'Preferred extended'}


TUNE = re.compile(r'\s*/\s*(comp|CS|slope)\s+tune$')


def clean_value(value):
    """Schematic values carry function labels ('100p / comp tune'); the order BOM wants the electrical value only."""
    return TUNE.sub('', value).strip()


def short_package(package):
    m = re.search(r'_(\d{4})_\d{4}Metric', package)
    return m.group(1) if m else package


def natural(ref):
    return [int(t) if t.isdigit() else t for t in re.split(r'(\d+)', ref)]


def category(refs):
    if not refs:
        return 'Extra'
    prefix = re.match(r'[A-Z]+', refs[0]).group()
    return CATEGORY.get(prefix, prefix)


def split_part(part):
    """'UNI-ROYAL 0603WAF1002T5E' -> ('UNI-ROYAL', '0603WAF1002T5E'); a trailing note in brackets is dropped."""
    text = re.sub(r'\s*\(.*?\)\s*$', '', part).strip()
    manufacturer, _, mpn = text.rpartition(' ')
    return manufacturer, mpn
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

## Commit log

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2026-07-07 Валидация настроек: WiFi роутера, пары мин/макс, починка AP-полей и баннеров ошибок
    - wifi_ssid/wifi_pass (роутер) теперь валидируются как ap_ssid/ap_pass:
    SSID до 32 символов, пароль пусто (открытая сеть) либо 8-63 (WPA2).
    При невалидных данных сохранение отклоняется, редирект ?error=wifi.
    - Добавлена подстраховка на сервере (clampPairInt/clampPairFloat):
    если границы мин/макс перепутаны местами, они автоматически меняются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
2026-09-22 Исправления гонок, валидации и веб-API
    Прошивка:
    - getLogSnapshot(): под спинлоком только memcpy, String собирается после выхода
    из критической секции (раньше — тысячи аллокаций с выключенными прерываниями)
    - /api/status: снимок строго под мьютексом, при неудачном захвате — 503
    (раньше в JSON уезжали неинициализированные переменные)
    - isPlausibleDateTime(): прежняя проверка (hour() <= 60) не ловила ничего,
    оба поля uint8_t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
2026-09-27 pcb: correct power MOSFET pin mapping and reverse input protection
    [InputPower.kicad_sch, LEDDrivers.kicad_sch, PCB_V1.kicad_pcb]
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2026-09-27 pcb: replace LT3756 with lower-cost AL8853 LED channels
    [BOM_schematic.csv, BOM_v0.1.csv, LEDDrivers.kicad_sch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]
2026-09-27 pcb: replace strip LED MOSFETs with DMT10H009LK3 DPAK parts
    [BOM_schematic.csv, BOM_v0.1.csv, LEDDrivers.kicad_sch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]
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2026-09-27 pcb: move board to 24 V input with 12 V aux buck and merged LED bar channel
    Revision 0.14 of PCB_V1 (see pcb/PCB_V1/REDESIGN_24V.md):
    - 24 V input on keyed XT60PW-M (pin 1 GND, pin 2 +24V); LM74700, input
    MOSFET and F901 removed; SMBJ26CA TVS; 220 uF/50 V bulk
    - ATM mini-blade fuses in XF-508P-B-B holders: F902 10 A loads, F903 7.5 A LED
    - new LMR16020 24 V -> 12 V aux buck (500 kHz) feeding PC fans, the
    UCC27524A heater gate driver and the TPS54202 3.3 V buck; TPS70950 removed
    - heater and pump on 24 V: SMBJ30A drain TVS, AO3422 + SS36 pump stage
    - LED CH1 panel keeps SRP1770TA/0.027 R/1k, switch now CSD19534Q5A;
    CH2 drives both identical bars in parallel (J721 || J731, 0.40 R);
    thi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
    [BOM_schematic.csv, BOM_v0.1.csv, Heater.kicad_sch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]
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2026-09-28 pcb: diagnose missing KiCad library tables
    [check_all.py]
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2026-09-28 pcb: price the whole v0.16 BOM from an LCSC snapshot
    - price_snapshot_v16.json: all 167 schematic references (plus the F902
    insert) with LCSC list-price tiers, minimum/multiple and stock on
    2026-09-28; representative parts for value-only passives; ECB EUR rate.
    - audit_bom_cost.py: requires a price line for every reference, applies
    MOQ/multiple for 1 and 5 boards, EUR totals, per-sheet breakdown,
    stock shortfalls; run by check_all.py (review/BOM_cost_v16.txt).
    - COST_REVIEW.md: USD 40.80 (EUR 35.86) per board, USD 71.82 order for
    one board; cost drivers, stock risks and cost-down candidates
    (about USD 5 without firmware changes).
    - v15 partial snapshot moved to history/.
    Co-Auth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
    [audit_bom_cost.py, check_all.py]
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2026-09-29 docs: record headless VPS mode and PM2 bot autostart
    - Remote desktop (kicad-vnc/kicad-novnc) and Tailscale Serve are off
    since 2026-09-29; add how to re-enable and disable them.
    - Document ss-bot under PM2 with the pm2-administrator systemd unit,
    the nvm PATH pin, cgroup pitfall and how to restart correctly.
    - List disabled sites and how to restore them from the saved dump.
    - Update reboot checks and the quick reference.
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2026-09-29 pcb: revision 0.19 cost-down in the schematic, same footprints
    Schematic and calculations only; PCB_V1.kicad_pcb is untouched on the
    user's request. All substitutions keep footprints and nets.
    - C716-C719, C726-C728: TDK C3225X7R2A106K250AC (X7R, published DC-bias
    curve 2.35 uF at 49 V) instead of Samsung CL32Y106KCV6PNE.
    - C104/C105/C401: Samsung CL21A226MPQNNNE X5R; C521/C710/C715/C725/
    C905/C906: Taiyo Yuden UMK325AB7106KMHP.
    - C602 shares CL21A106KAYNNNE with C201 (1.41 uF screen >= 1 uF);
    D601 shares SMBJ26CA with D901 (D_TVS symbol, 42.1 V clamp);
    R501/R511/R521 33R; F904 3 A shared with F721.
    - analyze_led_power/analyze_power_path/verify_netlist updated; price and
    JLC snaps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
    [BOM_schematic.csv, BOM_v0.1.csv, Heater.kicad_sch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]
2026-09-29 pcb: sync board values for revision 0.19
    sync_board.py applied the 17 schematic value/field changes of 0.19 to
    PCB_V1.kicad_pcb (C104/C105/C401, C201, C602, C716-C719, C726-C728,
    R501/R511/R521, D601, F904). A before/after comparison shows no moved,
    rotated or flipped part, no footprint change and no net change.
    check_all.py now passes completely; docs and v19 check log updated.
    [PCB_V1.kicad_pcb]
2026-09-30 pcb: revision 0.20 cost-down with new footprints and placement
    - RTC: DS3231MZ replaced by NXP PCF8563T/5 with an Epson FC-135 crystal
    (CL 12.5 pF), C304 18 pF C0G on OSCI, BAT54C supply OR (D303) and R307
    1k from the CR2032.
    - Boost switches Q711/Q721: AOS AOD66923 (DPAK) on a project footprint
    that keeps the S1/2/3 G4 D5 numbering; diodes D711/D721: Vishay SS5P10
    (TO-277A).
    - L101 cjiang FXL0630-100-M and L902 PROD PSPMAA0604-220M-ANP on the
    KiCad FXL0630 land.
    - LED switch areas and the RTC cluster re-placed (29 parts moved);
    ERC 0, DRC 0, 340 unrouted links.
    - Checks, price/JLC snapshots v20, reports, placement images and docs
    updated: USD 31.62 per board (29.52 for five bo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
    [BOM_schematic.csv, BOM_v0.1.csv, Heater.kicad_sch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]
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2026-09-30 pcb: correct auxiliary inductor RMS and RTC backup assumptions
    [BOM_v0.1.csv]
2026-09-30 pcb: use low-leakage RTC supply diode for revision 0.21
    [BOM_schematic.csv, BOM_v0.1.csv, Heater.kicad_sch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]
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2026-09-30 pcb: fix Python 3.11 BOM export and inductor margin explanation
    [export_bom.py]
2026-09-30 pcb: 3D models for power SMD parts and the microSD socket
    - models3d/power.py (CadQuery) generates simplified STEP models from the
    manufacturers' drawings: Littelfuse 451 fuses, Bourns SRP1265A and
    SRP1770TA, onsemi SO-8FL and the HRO TF-01A socket.
    - Project footprints Fuse_Littelfuse_451, L_Bourns_SRP1265A and
    microSD_HRO_TF-01A reference them via ${KIPRJMOD}.
    - sync_models.py attaches models to the board: GrowBox footprints from
    the project library, overrides for stock footprints whose KiCad 10
    model is missing (L711, Q601, U902, and BT301/SW201/SW202 once their
    models exist); it reports parts still without a model.
    - 11 board footprints updated; 13 connector/holder/button par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
    [PCB_V1.kicad_pcb]
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2026-09-30 pcb: attach all 3D models to the board and check them
    - sync_models.py --write attached the mechanical models (J901, J302,
    J501, J511, J521, J601, J711, J721, J731, F902, BT301, SW201, SW202);
    every placed part now has a 3D model.
    - verify_placement.py fails when a placed part has no model or a
    ${KIPRJMOD} model file is missing.
    - NT712/NT722 moved 0.1 mm away from R716/R726: 0.55 mm to the LED
    return pads, above the 0.5 mm LED48 clearance (the intermittent
    0.45 mm DRC report seen during PR #18).
    - Checked in the KiCad 10 GUI 3D viewer (top, bottom with BT301,
    isometric) and the footprint editor 3D view; kicad-cli renders.
    - F902 height stays calculated (17.15 mm); allow >= 18 mm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
    [PCB_V1.kicad_pcb]
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2026-10-01 pcb: routing scripts (power stage, Freerouting, completion router) and routing check
    route_power.py builds the power copper from tables (GND plane, +24 V pours on
    both outer layers, loads, LED boost loops, 12 V buck, ground islands, hand
    tracks and vias) and ties every other GND pad to In1; its finish stage swaps the
    islands for full-board GND pours and adds the +3V3 fill on In2.
    route_signals.py runs Freerouting 2.4.1 on a patched DSN (In1 as a power layer,
    keepouts under the script zones, narrower router widths for PWR12/PWR3V3/AUX24).
    route_complete.py joins what the router left open with a grid router that checks
    clearances with KiCad collision shapes. verify_routing.py checks the layer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
    [check_all.py, route_complete.py, route_power.py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]
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2026-10-01 pcb: JLCPCB DFM check and fabrication export
    check_fab.py compares the board with the published JLCPCB limits for a 4-layer
    1 oz board (tracks, vias, rings, holes, slots, hole spacing, hole to copper, mask
    webs, silkscreen, outline, stack); --fix-silk widens thin silkscreen lines.
    export_fab.py plots Gerber (X2, Protel extensions) and Excellon (separate PTH and
    NPTH, routed slots), normalises dates and versions in the headers, reads the
    files back against the board and builds a reproducible zip. check_all.py runs
    check_fab.py and keeps review/DFM_JLCPCB_<REV>.txt reproducible.
    [check_all.py, check_fab.py, export_fab.py]
2026-10-01 pcb: silkscreen at 0.15 mm and JLCPCB fabrication archive
    494 footprint silkscreen lines were 0.12 mm wide, below the JLCPCB minimum of
    0.15 mm; nothing else on the board changed (DRC 0 / 0 unconnected). Adds the
    Gerber and drill archive for JLCPCB (12 files), the DFM report (0 FAIL, 2 WARN)
    and the refreshed check log.
    [PCB_V1.kicad_pcb]
2026-10-01 pcb: check the JLCDFM categories, keep ties off neighbouring pads
    check_fab.py now also checks silkscreen against pads and holes (0.15 mm), vias
    touching or within 0.1 mm of a pad, tracks passing a pad without touching it,
    and through-hole pads within 0.5 mm of SMD pads; --fix-silk sets strokes to
    0.2 mm, cuts silkscreen away from pads and holes and nudges texts.
    route_power.tie_ground no longer places a ground via against a neighbouring
    pad of the same net (three ties overlapped one). fab_touchups.py records the
    one-off edits made on the routed board.
    [check_fab.py, export_fab.py, fab_touchups.py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]
2026-10-01 pcb: fix the findings of the JLCDFM report
    Removed a via 0.075 mm from two pads, redid three ground ties that overlapped
    neighbouring pads, moved four track corners that skimmed a pad of their own net
    and F301 by 0.1 mm (0.41 mm to BT301.2), set silkscreen strokes to 0.2 mm, cut
    silkscreen 0.15 mm away from pads and holes and nudged seven texts. DRC ignores
    lib_footprint_mismatch because the silkscreen of 29 library footprints now
    differs on purpose. DRC 0 / 0 unconnected; fabrication archive rebuilt.
    [PCB_V1.kicad_pcb]
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2026-10-02 enclosure: printable base and lid with wall ears, vents and snap fit
    Parametric CadQuery generator (pcb/enclosure/enclosure.py) built on the STEP export of
    PCB_V1 rev 0.22: 106x106x31.2 mm two-part PLA enclosure, 2.6 mm walls, lap joint with
    seven snap fingers, board resting on ledge blocks and held by eight lid ribs, wall windows
    from the connector bodies, ceiling access to J301/J201 and BOOT/RESET tubes, vent slots
    over the hot parts, four wall-mount ears. check_enclosure.py: no interference, minimum
    clearance 0.65 mm. STEP, print-oriented STL, fit-test coupons, renders and README included.
    The enclosure has not been printed yet.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
    [GrowBox_base.step, GrowBox_base_coupon_print.stl, GrowBox_base_print.stl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]
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2026-10-03 cheap-version: schematic substitutions from stock parts
    tools/make_cheap1.py generates the cheap-1 sheets from the PCB_V1 0.22 baseline:
    ST1S14 for LMR16020 (RT resistor removed, EN/FB divider recalculated), IRS4427S and
    IRL2505 for the heater, BSC146N10LS5 for the LED boost switches, SS56 diodes,
    KF301/FS1.5/KF2510/XH connectors, stock resistors and capacitors (Source field =
    stock:<id>). J901 XT60 is replaced by a screw terminal as decided. U101 TPS54202 and
    D711/D721 SS5P10 are kept because datasheets for ST1S10 and SBRT15U100SP5 were not
    available. ERC: 0 errors (one warning: footprint for the DTMSS-27 inductor pending);
    netdiff against PCB_V1: no connectivity differences among untouched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
    [Heater.kicad_sch, InputPower.kicad_sch, LEDDrivers.kicad_sch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]
2026-10-03 cheap-version: ST1S10, SBRT15U100SP5, datasheet checks, LED boost estimate
    With the datasheets supplied by the user: U101 TPS54202 -> ST1S10PHR (INH to VIN, SYNC to GND,
    L101 4.7 uH FXL0630-4R7-M, R102 31.6k, C103 repurposed as the VIN_A bypass); the 3.3 V sheet is
    redrawn in the stub-and-label style. D711/D721 -> SBRT15U100SP5 with a new GrowBox:Diodes_PowerDI5
    footprint (tools/make_footprints.py). IRS4427S pinout/levels, BSC146N10LS5 and DTMSS-27 data
    checked; tools/analyze_led_cheap.py re-runs the PCB_V1 LED boost model with the stock parts
    (all checks pass). Datasheet PDFs are not committed (datasheets/.gitignore). ERC: 0 errors,
    only the pending DTMSS-27 footprint warning; netdiff vs PC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
    [LEDDrivers.kicad_sch, cheap-version.kicad_sch]
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2026-10-03 cheap-version: unrouted board with a legal placement
    tools/make_board.py builds cheap-version.kicad_pcb from the PCB_V1 placement (copper removed, 55
    footprints replaced in place, R906 removed, nets from the cheap-1 netlist). tools/auto_place.py
    legalises it by simulated annealing on the courtyard boxes (wire length + leash to the V1 position,
    fixed: ESP32, connectors, battery holder, L711, J901, R716). placement_report.py: 0 overlaps.
    DRC: only unconnected items and silk remarks. Preview in review/Placement_cheap1_top.png.
    [cheap-version.kicad_pcb]
2026-10-03 cheap-version: save routing run 1 (Freerouting, no power pours yet)
    Board with the first autorouter pass: GND plane + 99 ground ties from tools/route_power.py, then
    tools/route_signals.py (Freerouting 2.4.1, 12 min, class widths MAIN24 2.0 / HEATER24 3.0 / LED_INPUT 2.0 /
    SWITCH 1.5 mm). 961 router items, DRC: no clearance or short violations, 10 unconnected items, silk remarks
    only. Not done yet: power pours for the 11.9 A trunk, loads, heater and boost nodes, the finish stage
    (GND/3V3 fills), the last 10 connections. Also adds the copper viewer (export_view.py, view.py).
    [cheap-version.kicad_pcb]
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2026-10-03 Reinforce cheap-version input and heater copper
    [cheap-version.kicad_pcb]
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2026-10-04 Reinforce cheap-version +24V distribution to the LED channels
    Replace the 95 mm 0.5 oz In2 +24V loop (2 mm) and the 43 mm 0.5 oz In2
    LED2_OUT run with outer-layer copper: +24V crosses the B.Cu +24V_LOADS band
    on F.Cu through ten vias, runs as a 3.6 mm B.Cu trunk with branches to the
    F711 and F721 feeds (F.Cu pours + via arrays), LED VIN/SW nodes become
    pours, LED2_OUT moves to a 1.2 mm B.Cu track.
    tools/reinforce_led.py is the repeatable stage, verify_led_copper.py checks
    widest continuous filled copper and via counts, freespace.py is the design
    aid. DRC with .kicad_dru: 0 errors, 0 unconnected.
    [cheap-version.kicad_pcb]
2026-10-04 cheap-version: CH1 for 80 W and UCC27524 heater driver
    R716 0.18 -> 0.12 ohm (1.667 A, 80 W at 48 V; the LED panel is rated up to
    120 W and is not fully loaded). analyze_led_cheap.py re-run: input current
    up to 4.61 A, inductor peak 6.26 A, OCP headroom 2.06 A, all model checks
    pass; about 96 W is the ceiling of this controller/inductor pair.
    U601 is the PCB_V1 UCC27524ADR again instead of the IRS4427S (2.5 V input
    threshold left 0.14 V of margin at ESP32 VOH): ENA tied to +12V, ENB to
    GND. Board side in tools/swap_heater_driver.py; generator, BOM and BUY
    lists follow (order estimate USD 34.69). Schematic ERC 0, schematic and
    board match pin by pin.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
    [BOM_cheap1.csv, BUY_cheap1.csv, Heater.kicad_sch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]
2026-10-04 cheap-version: widen the +12V fan line on In2 to 0.8 mm
    The two fans (0.68 A) were fed over about 45 mm of 0.5 mm / 0.5 oz In2
    (about +28 K by IPC-2221, an open question since PCB_V1). Segments outside
    the congested neck are now 0.8 mm (about +11 K); the 6.5 mm neck between
    two vias and an ESP_IO0 track stays 0.5 mm. B.Cu corridors are only
    0.3-0.7 mm wide there. tools/reinforce_12v.py is repeatable.
    [cheap-version.kicad_pcb]
2026-10-04 cheap-version: clean up the silkscreen (0 DRC warnings)
    tools/fix_silk.py (+ silk_model.py): removes 29 silk lines that crossed
    pads or the board outline (connector bodies overhanging the edge, L711 axis
    lines, touching C901/D901 outlines) and moves 63 reference designators and
    labels to the nearest free place (text as a box, 0.22 mm to other silk,
    0.12 mm to pads, 0.45 mm to the edge); none shrunk or hidden. Repeatable.
    DRC with .kicad_dru: 0 violations, 0 warnings, 0 unconnected (was 120
    silkscreen warnings). README updated for 80 W, the driver swap, +12V and
    silkscreen; top view in review/Board_top_cheap1.png.
    [cheap-version.kicad_pcb]
2026-10-04 cheap-version: JLCPCB DFM fixes (check_fab: 0 FAIL)
    pcb/check_fab.py on the cheap-1 board found: three crossing vias on the
    C901 pad (moved to 12 positions off the pad), nine same-net track corners
    that skim a pad (merged by tools/fab_touchups.py, LED2_RETURN corner moved
    onto the NT722 tie pad), silk strokes below 0.2 mm and silk within 0.15 mm
    of pads, holes and vias (check_fab --fix-silk, then fix_silk.py again with
    via-aware placement, 1.0 mm text, 0.2 mm strokes). The two silk labels with
    the PCB_V1 revision now say CHEAP-1.
    Result: check_fab 0 FAIL / 2 WARN (via ring 0.175 mm, same-net slits - same
    as PCB_V1), DRC with .kicad_dru 0 violations, 0 unconnected.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
    [cheap-version.kicad_pcb]
2026-10-04 cheap-version: local HF bypass C911 at the ST1S14 VIN pin
    The route from the input capacitors C905/C906 to U902 pin 7 is about 15 mm
    of 0.6 mm copper with two vias, half of it on B.Cu above the +3V3 flood
    instead of GND (hot-loop inductance 15 nH or more). C911, 100 nF 0603 from
    stock (a copy of C907), now sits on the bottom side right under pins 6/7:
    AUX_VIN pad on the existing B.Cu track, GND via beside it into In1, a
    second AUX_VIN via next to pin 7 closes the loop (about 5 nH). Schematic
    (generator), board (tools/add_c911.py), BOM (161 parts, 94 from stock),
    DRC 0 / check_fab 0 FAIL.
    [BOM_cheap1.csv, InputPower.kicad_sch, cheap-version.kicad_pcb]
2026-10-04 cheap-version: DC/DC loops, return paths, Gerber archive and bench checklist
    tools/analyze_dcdc_loops.py: hot-loop inductance from the copper (microstrip
    over In1 + vias): ST1S14 input 13 -> 4.8 nH with C911, ST1S10 4.4 nH, both
    boost stages 15-16 nH in total (SW overshoot about 6.5 V / 3 V on 100 V
    parts). tools/check_return_paths.py: In1 is one piece (92 % of the board),
    narrowest GND path from the input terminal 5.5-8.5 mm, switching nets not
    longer than 3 mm over a void. tools/check_sync.py compares schematic and
    board pin by pin; tools/run_checks.py runs ERC, DRC, sync, check_fab, the
    copper checks, the loop estimate and the Gerber check (9 of 9 pass).
    fab/cheap-version_cheap1_jlcpcb.z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
2026-10-04 cheap-version: put all 170 designators on the silkscreen
    103 of 170 reference designators sat on F.Fab/B.Fab at 0.8 mm: visible in
    KiCad, but absent from the silkscreen Gerber. fix_silk.py now moves every
    designator to the silkscreen of its side (168 F.Silkscreen, 2 B.Silkscreen),
    1.0 mm high, 0.2 mm stroke, and places each at the nearest free spot. The
    placement model compares strokes against strokes like DRC does (the earlier
    bounding-box model wasted room; silk_model.py keeps the parent shape alive, a
    dangling sub-shape crashed Collide). pcb/check_fab.py judged text against
    silk lines by the text box, which is stricter than DRC; it now uses strokes
    with the 0.15 mm silk gap (PCB_V1 result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
    [cheap-version.kicad_pcb]
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2026-10-04 cheap-version: short A4 assembly sheets (SMD and through-hole separately: one big placement picture and one positions+MPN table each)
    assembly/Assembly_cheap1_A4.pdf, 4 pages: the top-side placement picture of the SMD parts with every reference, polarity marks and zone grid (inset: bottom side with C911), the SMD table (reference designators next to MPN, one line per part type, 142 parts), the same two pages for the 17 through-hole parts (inset: BT301 on the bottom). tools/make_assembly_sheet.py builds it from the same board dump and BOM as the long document.
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2026-10-04 cheap-version: stencil jig hinge ear centred under its knuckle, pin bore left empty, scoop in the base for the frame knuckle
    The web (ear) of every knuckle was centred on x0 while the knuckle starts at x0, so the frame ear sat 18 mm to the left and filled 29 % of the pin bore of the frame knuckle; the frame knuckle also ran 106 mm3 into the base plate. The ears now have the knuckle's x range, the bore is cut from the joined solid, the base has a 0.5 mm clearance scoop for the central knuckle. STL, 3MF and the preview regenerated.
    [stencil_jig.scad, stencil_jig_base.stl, stencil_jig_base_geometry.3mf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]
2026-10-04 cheap-version: stencil jig printable without support (pin axis raised so the frame lies flat), hinge test sample
    The knuckle tube stuck out 1.85 mm below the bottom of the frame, so the frame hung in the air when printed (8792 mm2 of overhang, nothing on the bed). The pin axis is now one tube radius above the frame bottom plane, the ears are blocks under the whole tube, the frame ear ends 0.8 mm behind the axis so it clears the base edge, the pin bore is a teardrop. Overhang 70 mm2 in the frame, the frame opens 3..170 degrees without touching the base. The scoop in the base is no longer needed. Added a short hinge sample (stencil_jig_hinge_test_base/frame) for a quick test print. STL, 3MF an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
    [stencil_jig.scad, stencil_jig_base.stl, stencil_jig_base_geometry.3mf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]
2026-10-13 Fix heater/fan, watering and mode logic in firmware
    Climate:
    - Growing: hold fans at minimum while the heater is on. They used to ramp
    up to half range between "target - delta" and target and blow out the
    heat being produced, so a weak heater could stay on forever.
    - Drying: vent heat at target + 2 x hysteresis instead of at the heater
    switch-off threshold, where every heating cycle ended with the fans
    dumping the heat just gained.
    - Heater mode "never" now disables the heater in Drying too.
    - The mode is read only from the loop's settings copy; the separate
    atomic flag could disagree with it for up to a second.
    - LED and fan outputs are driven low at the start of setup(); they wer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
2026-10-13 Fix dashboard and settings UI issues
    Dashboard:
    - Header no longer pushes the Settings button off screen on phones: the
    time and the button stay on the first row, status badges wrap below.
    - Shows the mode: in Drying a "drying" badge replaces day/night and the
    cycle day.
    - Warns when the clock is not trusted (watering is disabled then) or the
    RTC is not answering.
    - Shows "no link" and dims the readings when the board stops answering;
    a hung request no longer blocks all further polling.
    - Chart: a single point no longer yields NaN, rows logged while the
    sensor was offline are skipped, auto-refresh follows the board date,
    the tooltip works with touch.
    Settings:
    - The page returns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
2026-10-13 Open settings on Climate, time picker for watering, lean Drying dashboard
    - Settings open on the Climate tab. The tab is restored only when the
    page comes back from a save (?saved / ?error), not on every visit.
    - Watering time is a single time picker like the light schedule; the
    form still submits watering_hour and watering_minute.
    - In Drying the dashboard hides the lamp and pump tiles, which are
    always off in that mode.
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
